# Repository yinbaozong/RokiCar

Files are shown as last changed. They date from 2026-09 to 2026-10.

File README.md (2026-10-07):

# RokiCar

**三轮全向移动，六边形车身，可打印、可改造的小型机器人。**

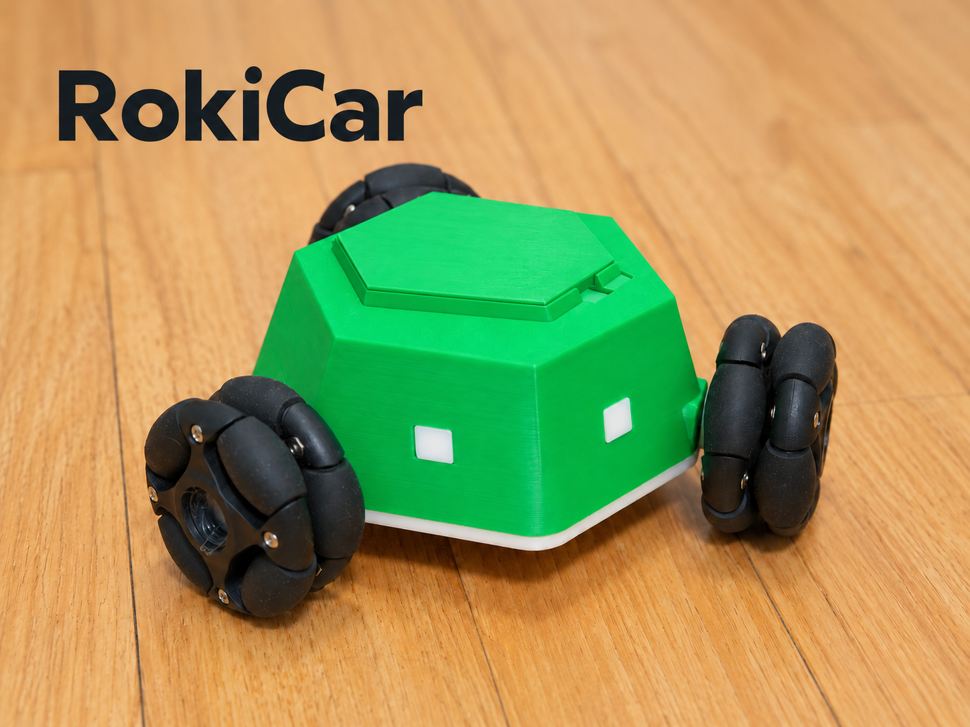
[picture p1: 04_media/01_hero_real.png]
实拍优化封面


当前：V8 外壳与顶盖、Android 1.22.0、三文件 MicroPython 程序。仓库公开，更新日期 2026-10-08。内部结构和轮组不变；顶盖取消定位销，保留一组磁吸。

## 下载与复刻

- [最新 Release / 全部附件](https://github.com/yinbaozong/RokiCar/releases/latest)
- [复刻指南 PDF](05_docs/RokiCar_复刻指南.pdf)：元器件、图片、装配、AI 刷写和首次校准。
- [Android APK 直接下载](https://github.com/yinbaozong/RokiCar/releases/latest/download/RokiCar-Controller-v1.22-debug.apk)
- [Roki 固件 ZIP](https://github.com/yinbaozong/RokiCar/releases/latest/download/RokiCar-Firmware-20261008.zip)
- [V8 模型 ZIP](https://github.com/yinbaozong/RokiCar/releases/latest/download/RokiCar-V8-Models.zip)
- [快速开始](05_docs/QUICK_START.md) · [物料与采购链接](05_docs/BOM.md) · [打印装配](05_docs/PRINT_AND_ASSEMBLY.md)

优先将固件交给能够访问本机终端和 USB 串口的 AI，例如 Codex、Claude Code、Trae、WorkBuddy，或 DeepSeek 搭配本地 Agent/Harness。安装 Python 和 mpremote，交给 AI 备份、上传、回读校验；用户确认重启和实车动作。详见 [刷写教程](05_docs/用户刷写教程.md) 和 [AI 提示词](05_docs/交给AI刷写.txt)。

## 最新机械与物料

- 车壳、顶盖：01_model/cad、01_model/print；原底壳为 01_model/cad/04_original_base.step。
- 顶盖每侧间隙 0.40 mm，围边厚 1.60 mm，无定位销。
- Ø8×2 mm 磁铁整车 10 颗：顶盖一组 2 颗、底壳四组 8 颗。
- N20 电机：6 V / 200 rpm，3 台；47 mm 全向轮 3 只；DRV8833 1 块。
- 电机螺丝 M1.6×3 mm 共 6 颗；BT 自攻规格为按孔位提出的试配建议，见 BOM。

## 最新接线与图片

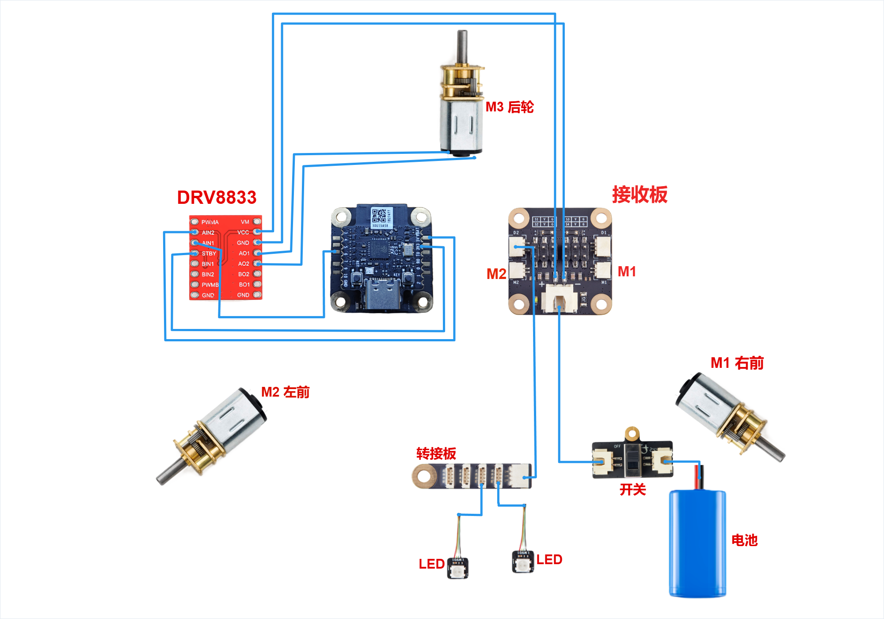
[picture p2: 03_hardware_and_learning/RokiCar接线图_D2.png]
作者确认的 D2 接线图


M1 右前、M2 左前、M3 后轮；LED 转接板 IN 接 D2，作者确认正常，固件灯控定义保持原样。逐项连接与电源说明见 [硬件接线](05_docs/HARDWARE_CONNECTIONS.md)。旧 SVG 和旧双驱动资料仅作学习参考。

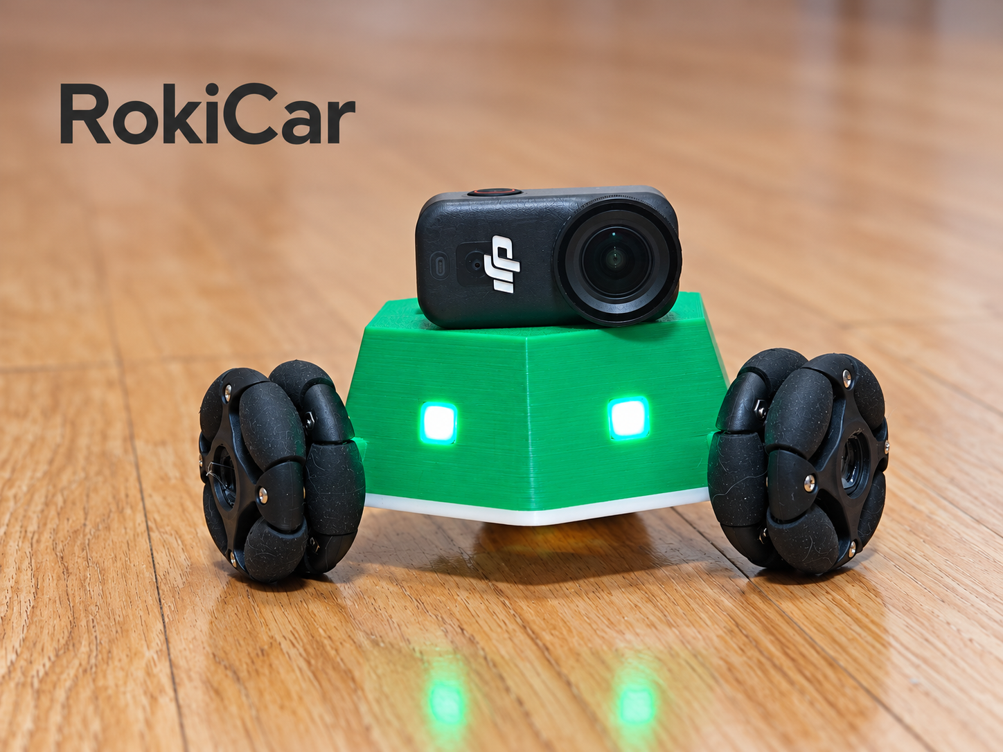
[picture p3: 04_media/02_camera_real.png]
相机搭载实拍优化


相机为额外配件，未交付图传、云台或专用磁吸相机支架。基础功能和实验功能见 [功能状态](05_docs/FEATURES_AND_ROADMAP.md)。

## 文档与验证

[项目手册](RokiCar_项目手册.md) · [MakerWorld 正文](05_docs/MAKERWORLD_DESCRIPTION.md) · [软件指南](05_docs/SOFTWARE_GUIDE.md) · [发布清单](05_docs/PUBLISH_FILES.md)

V8 几何与打印网格检查已记录在 01_model/docs。启动文件回归、语法与依赖检查通过；APK 使用既有 1.22.0 文件。本轮没有实车刷写或重新试打，按 PDF 完成文件回读、重启与架空校准后再低速落地。

原创内容采用 [MIT](LICENSE)，第三方组件见 [说明](THIRD_PARTY.md)。欢迎反馈打印配合、接线、兼容性和改造经验。

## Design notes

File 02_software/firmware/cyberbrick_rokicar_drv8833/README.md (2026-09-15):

# CyberBrick + DRV8833 三轮全向底盘测试程序

这个目录是给 CyberBrick Controller Core 用的 MicroPython 程序。

刷入后核心板会创建热点：

```text
WiFi: RokiCar
Password: 12345678
URL: http://192.168.4.1/
```

手机连接热点后打开网页，可以测试前进、后退、横移、旋转。

第一次测试必须把小车架空，不要让轮子落地。

## 硬件需求

- CyberBrick Controller Core x1
- DRV8833 双路电机驱动板 x2
- 6V DC 减速电机 x3
- 6V 电机电源

一块 DRV8833 只能控制两个 DC 电机。三轮小车需要两块 DRV8833。

## 引脚分配

| 轮子 | CyberBrick GPIO | DRV8833 输入 |
|---|---|---|
| W1 左前轮 | GPIO3 / GPIO2 | DRV-A AIN1 / AIN2 |
| W2 右前轮 | GPIO1 / GPIO0 | DRV-A BIN1 / BIN2 |
| W3 后轮 | GPIO21 / GPIO20 | DRV-B AIN1 / AIN2 |

如果某个轮子方向反了，优先改 `main.py` 里的 `MOTOR_SIGN`，不要急着重焊。

## 电机输出

| 轮子 | DRV8833 输出 |
|---|---|
| W1 左前轮 | DRV-A AO1 / AO2 |
| W2 右前轮 | DRV-A BO1 / BO2 |
| W3 后轮 | DRV-B AO1 / AO2 |

DRV-B 的 BO1/BO2 空着备用。

## 电源

| DRV8833 引脚 | 连接 |
|---|---|
| VM | 6V 电机电源正极 |
| GND | 6V 电源负极 + CyberBrick GND |
| STBY | CyberBrick 3V3 |
| NC | 不接 |

必须共地：CyberBrick GND 和 DRV8833 GND 要连在一起。

不要把电机直接接 CyberBrick。

## 上传

如果板子正在跑官方 CyberBrick RC 程序，需要先在串口里按 Ctrl+C 进入 REPL。

备份官方启动文件：

```powershell
mpremote connect COM9 resume fs cp :boot.py backup_boot.py
```

上传本程序：

```powershell
mpremote connect COM9 resume fs cp firmware\cyberbrick_rokicar_drv8833\main.py :main.py
mpremote connect COM9 resume fs cp firmware\cyberbrick_rokicar_drv8833\boot.py :boot.py
mpremote connect COM9 resume reset
```

恢复官方启动文件：

```powershell
mpremote connect COM9 resume fs cp backup_boot.py :boot.py
mpremote connect COM9 resume reset
```

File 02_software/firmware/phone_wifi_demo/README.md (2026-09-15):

# CyberBrick Phone WiFi Demo

这个 demo 只测试手机连接链路，不驱动电机。

刷入后 CyberBrick 会创建热点：

```text
WiFi: RokiCar-Demo
Password: 12345678
URL: http://192.168.4.1/
```

手机连接热点后打开网页，点击按钮时板载灯会闪一下，页面会显示收到的 `vx / vy / rot`。

## 上传

先关闭 CyberBrick 客户端，否则串口可能被占用。

查看可用串口：

```powershell
Get-PnpDevice -Class Ports
```

上传到指定串口，例如 `COM9`：

```powershell
.\firmware\phone_wifi_demo\upload.ps1 -Port COM9
```

如果要恢复官方 CyberBrick 程序，需要重新用 CyberBrick 官方客户端或官方固件流程刷回。

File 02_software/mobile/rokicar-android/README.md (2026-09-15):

# RokiCar Android

## 1.22.0

- 项目、APP、Android 包名和 Wi-Fi 热点统一改为 `RokiCar`。
- Android applicationId/namespace 改为 `com.rokicar.controller`，新版会与旧版并存安装。
- 固件升级后热点名统一为 `RokiCar`，控制地址仍为 `ws://192.168.4.1/ws`。

## 1.21.0

- 灯控首次连接自动补发状态查询（750ms 间隔，最多 10 次），不再依赖一次回复。
- 最新灯光命令未确认时每 500ms 重试，最多发送 4 次；旧状态不会覆盖最新操作，断线取消待发命令。
- AI 页只显示“待开发中”，关闭原生语音监听；返航顶部标注“实验功能”。
- 移除设置页闭环方形路径按钮及其事件处理。
- 使用 1.20 核心板程序，无需重新刷机。连接恢复、确认重试和断线取消三项模拟测试通过，仍需真机确认首次开灯效果。

## 1.20.0

- 设置页新增 RGB 灯光开关、颜色及亮度；两个灯同步变化。
- 需要同步上传 `firmware/cyberbrick_rokicar_m1m2_plus_drv8833/main.py`。
- CN301 IN 信号接 S1 / GPIO3，正极接稳压 5V，负极共地；D1/D2 仍用于第三电机。
- 协议类型 12，三个 int16 字段为 R/G/B（0–255）；全零关闭。四个输出统一设色，开机默认关闭。
- 灯控不更新运动超时计时；断线重连只读取灯状态，不重放开灯命令。
- 软件验证通过后仍需连接实物验证 CN301 输出和颜色顺序。

## 1.19.0

- Wi-Fi RSSI 保持每 `50ms` 读取和绘图，即 20Hz 界面刷新。
- 返航页新增读取频率、数值变化频率和数据年龄；原始值保持整数，平滑曲线显示一位小数。
- 灰线显示原始 RSSI，绿线显示滤波结果；返航趋势只接收真正发生变化的读数，避免重复缓存值被当成新证据。

## 1.18.0

- 横屏控制改为两只清晰的圆形摇杆，并显式绘制摇杆头，修复真机只显示轨道的问题。
- 左摇杆限定纵向油门，右摇杆限定横向转向；底部原地旋转按钮保持左右分区。

## 1.17.0

- 横屏双控制改为两个连续滑块：左侧纵向油门，右侧横向转向，支持双拇指同时拖动。
- 删除横屏四方向按键；原地左转和右转改为底部左右分区，退出键单独置顶。

## 1.16.0

- 横屏驾驶改为拇指分区：移动键固定贴近左侧，原地旋转和退出固定贴近右侧。
- 陀螺仪启动后自动开启平移，不再显示平移开关、姿态模拟和手动握姿校准。
- 航向转向独立切换：开启时只旋转，关闭后立即恢复前后左右平移。
- 返航终点 RSSI 默认修正为 `-35 dBm`，并修复首次启动被错误设成 `-20 dBm` 的问题。

## 1.15.0

- 双控制新增独立横屏驾驶界面：前进、后退、左移、右移、原地左转、原地右转和退出。
- 横屏控制按住才运动，松手、取消触摸、退出、后台和急停都会停车。
- 普通页面改为原生纵向滚动，横屏控制不再与页面滚动争夺手势。

## 1.13.0

- 陀螺仪模式新增手机航向跟随：校准时记录手机方位，左右旋转手机会让小车转向。
- 使用手机目标角度、虚拟车头积分和比例减速控制，误差进入 4° 死区后停止旋转。
- 航向数据超过 500ms 未更新时立即清零旋转命令。
- 这是无车载 IMU 的开环估算；轮胎打滑后可点“校准握姿”重新归零。

## 1.12.0

- “倾斜”模式改名为“陀螺仪”，固定输出纯平移与 `ROT=0`。
- 双控制转向上限由 27% 提升到 35%。
- 返航终点 RSSI 可手动设置，并显示最近约 60 秒实时曲线。
- RSSI 读取请求提升到 50ms；实际更新频率仍由 Android Wi-Fi 驱动决定。
- AI 页增加实时语音识别文字，并提示 RokiCar 无互联网时需要开启移动数据。

真正的无头模式需要车载 IMU 或其他车体航向反馈。当前手机传感器只能控制平移方向，无法测量车体因轮差产生的偏航。

## 1.11.0 测试版

安装包：`E:\三轮小车-麦克纳姆林\RokiCar-Controller-v1.11-debug.apk`

手机连接 `RokiCar` Wi-Fi 后打开 App。底部页面分为操控、AI、返航、设置与校准。

首次升级必须先把三只轮架空至少 10mm，然后在“设置与校准 > 完整电机标定向导”依次完成：

1. 点 M1、M2、外接板，确认它们对应 W1 左前、W2 右前、W3 后轮。
2. 观察每轮实际方向并选择“与图一致/相反”。当前故障现象高度提示 W3 需要反向，但请以实车观察为准。
3. 对每个物理端口运行 PWM 递增，连续稳定转动时点“已稳定”。
4. 架空预览前进、右移、原地右转，全部正确后保存。
5. 再运行三轮各五秒计圈，计算并保存速度增益。

方形测试现在按前进、右移、后退、左移执行，每边 5 秒、间隔 250ms，所有段 `ROT=0`。返航以反向轨迹为主，达到自适应 RSSI 目标立即停车；RSSI 连续恶化至少 3dB 时暂停并做四方向局部测向。

AI 语音配置只需一个阿里云百炼 API Key，模型为 `paraformer-realtime-v2`；DeepSeek Key 单独填写。心形、三角形、方形和五角星由 App 本地生成，执行前必须预览确认，并要求先完成距离标定。

原生 Android 控制器，直接连接 CyberBrick 的 `ws://192.168.4.1/ws`。不依赖 DCloud，项目可直接用 Android Studio 打开。

## 安装包

当前版本：`1.10.0`

```text
E:\三轮小车-麦克纳姆林\RokiCar-Controller-v1.10-debug.apk
```

USB 调试安装：

```powershell
adb install -r "E:\三轮小车-麦克纳姆林\RokiCar-Controller-v1.10-debug.apk"
```

手机先连接 `RokiCar` Wi-Fi，再打开 App。界面底部有四个分栏：

- `操控`：单摇杆、双控制、手机倾斜、速度档位和原地旋转。
- `AI 助手`：本地唤醒词“小麦小麦”、多轮对话记录、文字指令及云端配置。
- `返航`：轨迹回放、Wi-Fi 辅助判断、方形路径和距离标定。
- `设置`：重新连接和三轮五秒计圈校准。

红色方形按钮是全局急停，切换任何分栏也会先停车。

返航会从第一次移动开始持续保存最多十分钟的控制轨迹，App 重启后仍可恢复。返回时先按原速度、反序执行尚未回放的轨迹，并逐段删除已完成部分；只有回放后的信号明显弱于出发点基线，才用四方向 Wi-Fi 试探作局部修正。Wi-Fi RSSI 只能辅助判断远近，不能提供绝对方向。

闭环方形测试位于 `设置`，按前进、右移、后退、左移运行，每边 3.5 秒，理论终点为起点。没有编码器或视觉定位时，落地误差仍需通过轮速校准降低，软件无法测得真实厘米级位置。

## 小麦语音

语音链路为：本地 `sherpa-onnx` 唤醒词检测 → 阿里云一句话识别 → DeepSeek 受限工具决策 → App 校验动作 → CyberBrick 执行 → Android TTS 回复。

1. 在 `AI 助手 > AI 云端配置` 填写阿里云 AppKey 和临时 Token。
2. 填写 DeepSeek API Key。未填写时只支持本地基础移动指令。
3. 点击“安全保存到本机”，再开启“小麦小麦”监听并允许麦克风权限。
4. 连续说“小麦小麦”，听到“我在”后再说完整要求。

密钥使用 Android Keystore 加密保存，不写入 APK。阿里云临时 Token 过期后需要重新填写。DeepSeek 只能选择受限的移动、旋转、停车和返航工具，单次运动最长五秒，不能直接生成 PWM 或 GPIO 指令。

## 构建

```powershell
.\gradlew.bat :app:assembleDebug
```

Gradle 输出：

```text
app\build\outputs\apk\debug\app-debug.apk
```

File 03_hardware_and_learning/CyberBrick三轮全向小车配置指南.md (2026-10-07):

> 历史学习资料：当前接线、灯口和轮位请以 [最新 D2 接线说明](../05_docs/HARDWARE_CONNECTIONS.md) 与 [接线图](RokiCar接线图_D2.png) 为准。

# CyberBrick 三轮全向小车配置指南

日期：2026-07-05

## 1. 先说结论

用 CyberBrick 复刻三轮全向小车是可行的，但最终版需要写一点 MicroPython。

原因很简单：CyberBrick 官方接收扩展板只有 M1、M2 两路 DC 电机口，而三轮全向车需要 3 个独立 DC 电机同时正反转、调速。官方图形化配置适合两轮差速车、舵机、灯效和简单动作；三轮全向车需要把摇杆输入实时换算成三个轮子的速度，这一步就是三轮逆运动学，必须用代码做。

你不需要从零学完整编程。我们采用“官方 CyberBrick 配置 + 小段 MicroPython 控制程序”的路线。

## 2. 推荐架构

```text
CyberBrick 发射端
  核心板 + 发射扩展板 + 摇杆/按键
        |
        | CyberBrick 无线通信
        v
CyberBrick 接收端
  核心板 + 接收扩展板
        |
        | GPIO / PWM 信号
        v
外部三路电机驱动板
        |
        v
三个 DC 减速电机 + 47 mm 全向轮
```

接收扩展板的 M1/M2 可以先用来做两路电机验证，但最终车最好用外部三路驱动板统一驱动三个电机。

## 3. 为什么不能只靠官方接收板

官方接收扩展板的输出资源大致是：

- 2 路 DC 电机口：M1、M2。
- 4 路舵机口：S1-S4。
- 2 路 WS2812 灯口。

三轮全向底盘需要：

- W1 左前轮：一路 DC 电机。
- W2 右前轮：一路 DC 电机。
- W3 后轮：一路 DC 电机。

也就是至少 3 路 DC 电机。舵机口不能直接当普通 DC 电机 H 桥用，因为普通 DC 电机需要方向控制和 PWM 功率驱动。

## 4. 控制方式选择

### 推荐第一版：CyberBrick 遥控器控制

先用你手里的 CyberBrick 发射端做遥控器。这样不需要先做手机 App，调试更快。

建议遥控器输入：

- 左摇杆 X：左右平移。
- 左摇杆 Y：前后平移。
- 右摇杆 X 或单轴摇杆：原地旋转。
- 一个按钮或三段开关：速度档位。

### 第二版：手机控制

等底盘稳定跑起来后，再做手机控制。手机控制可以走 WiFi UDP 或 CyberBrick 自带 App/配置能力，但不建议第一步就上手机控制，因为变量太多。

## 5. 配置步骤

### 第 1 步：确认官方 CyberBrick 能正常配对

在 CyberBrick 桌面端或手机端中：

1. 给发射端核心板接发射扩展板。
2. 给接收端核心板接接收扩展板。
3. 分别上电。
4. 在 CyberBrick 软件里找到两个核心板。
5. 完成发射端和接收端配对。

这一步只验证官方无线链路，不接三轮底盘。

### 第 2 步：用官方 M1/M2 做两电机测试

先只接两个电机到接收板 M1/M2。

目标：

- 摇杆能控制 M1 正反转。
- 摇杆能控制 M2 正反转。
- 断开摇杆时电机能停止。

这一步是为了确认 CyberBrick 的发射、接收、电机口、供电都正常。

### 第 3 步：接外部三路电机驱动板

最终建议用外部三路驱动板，或用两个 DRV8833 双路模块组成 3 路。

每个普通 DC 电机需要两个控制信号：

```text
W1: IN1, IN2
W2: IN3, IN4
W3: IN5, IN6
```

供电原则：

- 电机电源单独用 6 V 降压模块。
- CyberBrick 按官方方式供电。
- CyberBrick GND 和电机驱动板 GND 必须共地。
- 不要用 CyberBrick 核心板的小电源脚直接给三个电机供电。

### 第 4 步：写 MicroPython 三轮混控

代码要做三件事：

1. 读取发射端摇杆值：`vx`、`vy`、`rot`。
2. 根据三轮逆运动学算三个轮子的速度。
3. 输出到三路电机驱动板。

本项目的定版轮位公式：

```python
w1 = -0.5 * vx - 0.866 * vy + rot_gain * rot
w2 = -0.5 * vx + 0.866 * vy + rot_gain * rot
w3 =  1.0 * vx               + rot_gain * rot
```

然后把 `w1/w2/w3` 限幅到 `-1.0 ~ +1.0`，再变成 PWM。

### 第 5 步：悬空测试

小车先架起来，轮子不要碰桌面。

测试顺序：

1. 前进：两个前轮一正一反，后轮接近不动。
2. 右移：后轮贡献最大，两个前轮同向小一点。
3. 原地旋转：三个轮子同向转。
4. 松开摇杆：三个轮子全部停止。

如果某个轮方向反了，只改程序里的符号，不先改结构。

### 第 6 步：低速落地测试

第一次落地时把最大 PWM 限制在 40%。

测试顺序：

1. 原地旋转。
2. 前后移动。
3. 左右横移。
4. 斜向移动。
5. 边移动边旋转。

底盘能稳定运动后，再装手机托盘和舵机云台。

## 6. 你需要准备的东西

必需：

- CyberBrick 发射端核心板 + 发射扩展板。
- CyberBrick 接收端核心板 + 接收扩展板。
- 三个 6 V 200 RPM 左右 DC 减速电机。
- 三个 47 mm 全向轮。
- 外部三路 DC 电机驱动板，或 DRV8833 双路模块 x2。
- 6 V 3 A 以上降压模块。
- 电池和主开关。

建议：

- 先不要接手机和云台。
- 先不要做完整外壳。
- 先把三轮底盘跑顺。

## 7. 配置路线选择

### 不写代码

只能做两轮差速车，或者做非常别扭的两电机/舵机混合方案。不适合三轮全向底盘。

### 写少量代码

推荐。使用 CyberBrick 官方发射/接收链路，只在接收端写三轮混控。代码量不大，但能得到真正的三轮全向运动。

### 完全自定义手机控制

后续版本再做。可以让 CyberBrick 核心板开 WiFi 或接收 UDP，但第一版不推荐先做手机控制。

## 8. 当前下一步

现在不要急着写完整程序。下一步按这个顺序做：

1. 在 CyberBrick 软件里完成发射端和接收端配对。
2. 用官方 M1/M2 接两个电机，确认遥控链路和电机输出正常。
3. 选定外部电机驱动板型号。
4. 确认 CyberBrick 核心板可用 GPIO 引脚。
5. 再写三轮混控 MicroPython。

这样走最稳，不会一上来就把机械、电源、无线、代码四件事搅在一起。

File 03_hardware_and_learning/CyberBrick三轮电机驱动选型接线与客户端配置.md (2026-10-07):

> 历史学习资料：当前接线、灯口和轮位请以 [最新 D2 接线说明](../05_docs/HARDWARE_CONNECTIONS.md) 与 [接线图](RokiCar接线图_D2.png) 为准。

# CyberBrick 三轮电机驱动选型、接线与客户端配置

日期：2026-07-05

## 1. 最终推荐

买两个 `DRV8833 双路直流电机驱动模块`。

原因：

- 一个 DRV8833 模块可以驱动 2 个 DC 电机。
- 两个模块一共 4 路，用其中 3 路，剩 1 路备用。
- 模块很小，容易塞进 135 mm 轮心圆底盘。
- 支持 3.3 V 逻辑，适合 CyberBrick 核心板的 ESP32-C3。
- 电机电压覆盖 6 V 小减速电机场景。
- 比 L298N 小很多，效率也高很多。

搜索关键词：

```text
DRV8833 双路电机驱动模块
DRV8833 2路 直流电机驱动板 3V 10V
DRV8833 dual motor driver module
```

不要买：

- L298N：太大、压降大、发热，低压小车不划算。
- L9110S：便宜但余量小，不适合你后面 700-800 g 负载。
- 只写“电机驱动板”但没写芯片和电流参数的杂板。

## 2. 备选方案

如果你想一块板解决，也可以买 `四路 TB6612FNG 直流电机驱动板`。

搜索关键词：

```text
四路 TB6612FNG 直流电机驱动板
TB6612 四路电机驱动模块
Quad Motor Driver TB6612FNG
```

优点是一块板更整洁。缺点是板子更大，线也不一定少；很多四路板是 Arduino Shield 形式，不适合直接塞进你现在这个紧凑底盘。

所以第一版还是推荐：`DRV8833 x2`。

## 3. 重要参数

按官方和常见模块资料：

| 驱动 | 路数 | 电机电压 | 单路电流 | 适合本项目 |
|---|---:|---:|---:|---|
| DRV8833 双路模块 | 2 | 约 2.7-10.8 V | 约 1.2-1.5 A 连续，2 A 左右峰值 | 推荐 |
| TB6612FNG 双路模块 | 2 | 约 2.5-13.5 V | 约 1.2 A 连续，3.2 A 峰值 | 可用 |
| 四路 TB6612FNG 板 | 4 | 约 2.5-13.5 V | 约 1.2 A 连续 | 可用但偏大 |
| L298N | 2 | 高压范围大 | 发热大、压降大 | 不推荐 |

你买电机时要看堵转电流。如果单电机堵转电流明显超过 1.5-2 A，就不要用小 DRV8833，得换更大电流的驱动。

## 4. 接线总原则

三件事必须记住：

1. 电机不能直接接 CyberBrick 核心板。
2. 电机电源和 CyberBrick 供电可以分开，但 GND 必须共地。
3. 先只接一个电机测试，确认方向和发热，再接三个。

推荐供电：

```text
2S 电池 7.4 V
  |
  +-- 6 V 降压模块 --> DRV8833 VM / 电机电源
  |
  +-- CyberBrick 官方供电 / 5 V 稳压

CyberBrick GND 必须连接 DRV8833 GND
```

## 5. DRV8833 x2 接线表

这里假设两个 DRV8833 模块分别叫 `DRV-A` 和 `DRV-B`。

### 电机输出

| 轮子 | 驱动模块 | 输出端 |
|---|---|---|
| W1 左前轮 | DRV-A | AOUT1 / AOUT2 |
| W2 右前轮 | DRV-A | BOUT1 / BOUT2 |
| W3 后轮 | DRV-B | AOUT1 / AOUT2 |
| 备用 | DRV-B | BOUT1 / BOUT2 空着 |

如果轮子方向反了，优先在程序里改符号；也可以交换该电机的两根输出线。

### 电源

| DRV8833 引脚 | 接哪里 |
|---|---|
| VM / VIN / Motor V+ | 6 V 电机电源正极 |
| GND | 电机电源负极 + CyberBrick GND |
| VCC | 如果模块有 VCC，接 CyberBrick 3V3 |
| SLEEP / nSLEEP | 如果模块有这个脚，接 3V3 拉高 |

不同商家的 DRV8833 模块命名不完全一样。只要认准：电机电源、地、输入脚、输出脚。

## 6. CyberBrick 到 DRV8833 的信号线

第一版建议用 6 根控制线，每个电机 2 根：

| 轮子 | DRV8833 输入 | CyberBrick 建议 GPIO | 物理取线建议 |
|---|---|---:|---|
| W1 左前轮 | IN1 | GPIO3 | 接收板 S1 信号脚或核心板焊盘 |
| W1 左前轮 | IN2 | GPIO2 | 接收板 S2 信号脚或核心板焊盘 |
| W2 右前轮 | IN1 | GPIO1 | 接收板 S3 信号脚或核心板焊盘 |
| W2 右前轮 | IN2 | GPIO0 | 接收板 S4 信号脚或核心板焊盘 |
| W3 后轮 | IN1 | GPIO21 | 核心板右侧焊盘 |
| W3 后轮 | IN2 | GPIO20 | 核心板右侧焊盘 |

注意：

- 如果使用 S1-S4 的信号脚，就不要在 CyberBrick 客户端里把 S1-S4 配置成舵机。
- S1-S4 的 V 脚不要接到 DRV8833 的 VM。DRV8833 的 VM 要接 6 V 电机电源。
- GPIO20/GPIO21 是串口相关脚。如果后面发现调试串口冲突，可以把 W3 改到 GPIO4/GPIO5，但那会和官方 M1 电机控制脚重叠，需要实测。
- GPIO8 是板载 RGB LED，GPIO9 是用户按键，不建议拿来驱动电机。

## 7. CyberBrick 客户端怎么配置

### 7.1 先做官方链路验证

先不要接外部驱动板。

在 CyberBrick 客户端里：

1. 新建项目。
2. 添加/配对发射端核心板。
3. 添加/配对接收端核心板。
4. 发射端添加摇杆模块。
5. 接收端先用官方 M1/M2 接两个电机做测试。
6. 确认摇杆能控制两个电机正反转。

这一步只证明 CyberBrick 发射、接收、供电、电机口都正常。

### 7.2 外部三路驱动时的配置

最终三轮全向底盘时：

- 接收端不要再把 M1/M2 当正式驱动。
- S1-S4 如果被我们拿来当 GPIO，就不要配置成舵机。
- 在接收端添加 `Code`，用于测试外部 GPIO 和驱动板。

客户端大致流程：

1. 进入你的项目。
2. 选择接收端 Receiver。
3. 找到 `Code` 或代码模块。
4. 点击 `Add` 新增代码片段。
5. 粘贴测试代码。
6. 给发射端按钮添加事件。
7. 事件动作选择 `Code`，选择刚才的代码片段。
8. 保存并发送配置到设备。
9. 按按钮触发测试。

## 8. 客户端 Code 测试片段

下面这段只用于测试外部驱动板，不是最终摇杆控制。

先把小车架空，轮子不要碰桌面。

```python
from machine import Pin, PWM
import uasyncio as asyncio

FREQ = 1000
MAX_DUTY = 65535

W1A = PWM(Pin(3), freq=FREQ)
W1B = PWM(Pin(2), freq=FREQ)
W2A = PWM(Pin(1), freq=FREQ)
W2B = PWM(Pin(0), freq=FREQ)
W3A = PWM(Pin(21), freq=FREQ)
W3B = PWM(Pin(20), freq=FREQ)

def duty(x):
    x = max(0, min(1, abs(x)))
    return int(MAX_DUTY * x)

def set_pair(a, b, speed):
    if speed > 0:
        a.duty_u16(duty(speed))
        b.duty_u16(0)
    elif speed < 0:
        a.duty_u16(0)
        b.duty_u16(duty(speed))
    else:
        a.duty_u16(0)
        b.duty_u16(0)

def stop_all():
    set_pair(W1A, W1B, 0)
    set_pair(W2A, W2B, 0)
    set_pair(W3A, W3B, 0)

set_pair(W1A, W1B, 0.35)
set_pair(W2A, W2B, 0)
set_pair(W3A, W3B, 0)
await asyncio.sleep(1.5)
stop_all()
```

测试顺序：

1. 改代码，只让 W1 转。
2. 改代码，只让 W2 转。
3. 改代码，只让 W3 转。
4. 每个轮子都能正反转后，再做混控。

## 9. 为什么客户端 Code 不能直接完成最终摇杆混控

我看了 CyberBrick 官方 RC 代码。官方 `MotorsController` 只封装了 M1/M2 两个电机；客户端的 Code 片段可以触发运行代码，但默认执行环境没有直接把实时摇杆 `remote_data` 暴露给代码片段。

所以：

- Code 片段适合做外部驱动板测试、固定动作、启动/停止脚本。
- 真正的三轮全向连续摇杆控制，最好做成接收端自定义 MicroPython 程序，或者修改官方 `app_rc` 里的控制逻辑。

这不是坏事。我们仍然先用客户端完成配对、摇杆校准和硬件验证，然后进入自定义代码阶段。

## 10. 最终三轮混控逻辑

等三个电机都测试通过后，最终代码要做：

```python
w1 = -0.5 * vx - 0.866 * vy + rot_gain * rot
w2 = -0.5 * vx + 0.866 * vy + rot_gain * rot
w3 =  1.0 * vx               + rot_gain * rot
```

然后归一化限幅：

```python
scale = max(1, abs(w1), abs(w2), abs(w3))
w1 /= scale
w2 /= scale
w3 /= scale
```

最后分别输出到三个 DRV8833 通道。

## 11. 我的下一步建议

现在按这个顺序做：

1. 买 `DRV8833 双路电机驱动模块 x2`。
2. 先只接 W1 一个电机。
3. 用客户端 Code 片段测试 W1 正反转。
4. 再接 W2、W3。
5. 三个轮子单独测试都通过后，再写真正的三轮混控程序。

不要一开始就把三个电机、手机、舵机、电池全接上。先让一个轮子听话，整车就稳了一半。

## 12. 参考资料

- DRV8833 官方数据手册：<https://www.ti.com/lit/gpn/DRV8833>
- Pololu DRV8833 双路驱动说明：<https://www.pololu.com/product/2130>
- SparkFun TB6612FNG 接线指南：<https://learn.sparkfun.com/tutorials/tb6612fng-hookup-guide/all>
- DFRobot 四路 TB6612FNG 驱动板：<https://wiki.dfrobot.com.cn/_SKU_DRI0039_Quad_Motor_Driver_Shield_for_Arduino%E5%9B%9B%E8%B7%AF%E7%9B%B4%E6%B5%81%E7%94%B5%E6%9C%BA%E9%A9%B1%E5%8A%A8%E6%89%A9%E5%B1%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>
- CyberBrick 官方控制核心源码：<https://github.com/CyberBrick-Official/CyberBrick_Controller_Core>
- CyberBrick MotorsController API：<https://makerworld.com/en/cyberbrick/api-doc/cyberbrick_core/lib/MotorController.html>

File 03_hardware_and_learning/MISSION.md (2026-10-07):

> 历史学习资料：当前接线、灯口和轮位请以 [最新 D2 接线说明](../05_docs/HARDWARE_CONNECTIONS.md) 与 [接线图](RokiCar接线图_D2.png) 为准。

# Mission: Three-Wheel Omni Car

## Why
Build a cost-effective three-wheel omni car based on Bambu CyberBrick that can carry a phone, camera/servo payload, and be controlled from a phone. Learning the kinematics matters because the chassis will not move correctly unless the wheel layout, motor directions, and control code agree.

## Success looks like
- Model a compact three-wheel chassis from fixed wheel-center coordinates.
- Explain why a desired chassis motion becomes three different wheel speeds.
- Translate joystick commands into motor PWM values on CyberBrick MicroPython.
- Debug wrong wheel directions without redesigning the chassis.

## Constraints
- Keep the design cost-effective and printable.
- Use a three-layer structure: lower mechanical/electrical plate, middle CyberBrick/control plate, upper phone/camera/servo payload.
- Prefer deterministic diagrams, HTML simulation, and code-native artifacts over decorative visuals.

## Out of scope
- Full closed-loop encoder control for the first chassis version.
- FPV video streaming on the first driveable prototype.

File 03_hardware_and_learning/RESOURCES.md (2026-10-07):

> 历史学习资料：当前接线、灯口和轮位请以 [最新 D2 接线说明](../05_docs/HARDWARE_CONNECTIONS.md) 与 [接线图](RokiCar接线图_D2.png) 为准。

# Three-Wheel Omni Car Resources

## Knowledge

- Local note: `C:\Users\win11\Documents\Obsidian Vault\三轮全向麦克纳姆轮小车复刻指南 - Three-wheel Omni-wheel Car Replication Guide.md`
  Use for: the project-specific replication notes, motor-speed assumptions, UDP protocol, and existing ESP32/UniApp examples.
- Local code: `E:\三轮小车-麦克纳姆林\相关资料\SLC_Camera_UDP_IMU\SLC_Camera_UDP_IMU\SLC_Camera_UDP_IMU.ino`
  Use for: the existing three-wheel UDP protocol, ESP32 motor output mapping, and IMU correction pattern.
- CyberBrick official repository: https://github.com/CyberBrick-Official/CyberBrick_Controller_Core
  Use for: CyberBrick MicroPython capabilities, ESP32-C3 quick reference, PWM, WiFi, and socket behavior.

## Wisdom

- First real-world test should be low-speed desk testing with the car suspended first, then wheels on the table. Use for: validating motor signs, wheel placement, and center-of-mass safety before adding the phone payload.

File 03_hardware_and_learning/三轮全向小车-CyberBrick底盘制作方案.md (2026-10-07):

> 历史学习资料：当前接线、灯口和轮位请以 [最新 D2 接线说明](../05_docs/HARDWARE_CONNECTIONS.md) 与 [接线图](RokiCar接线图_D2.png) 为准。

# 三轮全向小车 CyberBrick 底盘制作方案

日期：2026-06-28

## 0. 结论先行

你的目标是桌面为主、偶尔地面、整车约 800 g，并且希望用手机联网控制。方案定版如下：

- 轮子定为 47 mm 全向轮。
- 电机定为 6 V 200 RPM 金属减速电机，后续用软件限速做桌面低速档。
- 底盘采用三轮 Kiwi/Omni 布局，三个轮子中心在等边三角形顶点。
- 建模用的轮心圆半径 R = 67.5 mm，轮心圆直径 D = 135 mm。
- 47 mm 轮装上后的实际占地外接半径约 91 mm，实际占地外接直径约 182 mm。
- CyberBrick 标准接收扩展板只有 2 路 DC 电机口，三轮全向底盘需要 3 路电机，所以推荐方案是“CyberBrick 核心板 + 自制 3 路电机驱动小板”，不用标准接收板直接驱三轮。
- 第一版不做摄像头，不做闭环编码器；手机连小车 WiFi AP，发送 UDP 控制包，CyberBrick ESP32-C3 用 MicroPython 解算三轮速度并输出 PWM。

一句话版本：47 mm 轮 + 轮心圆直径 135 mm + 6 V 200 RPM 减速电机 + DRV8833 x2 + CyberBrick 核心板，是最稳的桌面复刻路线。

## 0.1 建模定版尺寸

坐标系定义：车体中心 C = (0, 0)，X 向右，Y 向前；两个前轮在前方，单后轮在后方。

| 项目 | 定版值 |
|---|---:|
| 轮子直径 | 47 mm |
| 轮子半径 | 23.5 mm |
| 轮心圆半径 R | 67.5 mm |
| 轮心圆直径 D | 135 mm |
| 三个轮心构成的等边三角形边长 | 116.9 mm |
| 装轮后的占地外接半径 | 91 mm |
| 装轮后的占地外接直径 | 182 mm |
| 上层手机托盘建议尺寸 | 175 x 90 mm |
| 手机放置方向 | 160 mm 长边沿车体前后方向，70 mm 宽边沿左右方向 |

轮心坐标：

| 轮位 | 极角 | X | Y | 电机轴/轮轴方向 | 轮子滚动方向 |
|---|---:|---:|---:|---:|---:|
| W1 左前轮 | 150 deg | -58.5 mm | +33.75 mm | 150 deg 径向 | 60 deg 切向 |
| W2 右前轮 | 30 deg | +58.5 mm | +33.75 mm | 30 deg 径向 | 120 deg 切向 |
| W3 后轮 | 270 deg | 0 mm | -67.5 mm | 270 deg 径向 | 0 deg 切向 |

建模时先画一个半径 67.5 mm 的辅助圆，把三个轮轴中心放在上表坐标。电机轴线从车体中心指向对应轮心，轮子的主动滚动方向与这条径向线垂直。电机正反方向不用在结构上纠结，最后在程序里调符号。

135 mm 轮心圆会比 150 mm 更紧凑，适合你的三层结构。注意一个边界：上层舵机、相机和手机的合成重心尽量不要超过车体中心前方 34 mm；如果云台很重，就把电池稍微后移一点来配平。

## 1. 轮径与电机转速选择

速度公式：

```text
车轮线速度 v = RPM / 60 * pi * 轮径
```

### 1.1 47 mm 全向轮

| 电机输出转速 | 理论最高车速 | 桌面 1.2 m 横穿时间 | 判断 |
|---:|---:|---:|---|
| 150 RPM | 0.37 m/s | 3.2 s | 很适合桌面，稳 |
| 187 RPM | 0.46 m/s | 2.6 s | 桌面/地面兼顾，推荐 |
| 200 RPM | 0.49 m/s | 2.4 s | 推荐，采购更常见 |
| 300 RPM | 0.74 m/s | 1.6 s | 桌面偏快，需要限速 |
| 400 RPM | 0.98 m/s | 1.2 s | 桌面太快，不推荐满速 |

47 mm 的好处是通过能力、抓地和机械空间都更好。带手机和几个舵机时，28 mm 会显得有点低趴，电机和底盘很容易贴近桌面。

最终定版：买 6 V 200 RPM 金属减速 N20/030 小减速电机。200 RPM 满速约 0.49 m/s，桌面调试时把最大 PWM 限到 60-70%，需要地面巡航时再放开。

### 1.2 为什么不选 28 mm 全向轮

| 电机输出转速 | 理论最高车速 | 桌面 1.2 m 横穿时间 | 判断 |
|---:|---:|---:|---|
| 150 RPM | 0.22 m/s | 5.5 s | 偏慢 |
| 300 RPM | 0.44 m/s | 2.7 s | 推荐 |
| 400 RPM | 0.59 m/s | 2.0 s | 可用，但需限速 |
| 500 RPM | 0.73 m/s | 1.6 s | 桌面偏快 |

本项目不采用 28 mm 轮。原因是手机和云台会把整车推到 700-800 g，28 mm 轮轴心只有 14 mm，高度、离地间隙和电机安装空间都偏紧，最后省下的尺寸不值得。

### 1.3 扭矩结论

800 g 平面移动不是大扭矩场景，真正要防的是启动打滑、堵转发热和结构变形。实际采购时看这三个指标：

- 额定电压：6 V 优先。
- 堵转电流：单电机最好不超过 1.5-2.0 A，方便用 DRV8833/TB6612。
- 输出轴：3 mm D 轴或常见 N20 D 轴，方便配联轴器。

不要买裸 030/130 高速电机直接带轮，一定买“电机 + 减速箱一体”的减速电机。

## 2. CyberBrick 适配方案

官方 CyberBrick 接收扩展板适合两轮差速车：它有 2 路 DC 电机口、4 路舵机口、2 路 WS2812 灯口。三轮全向车需要 3 路可正反转、可调速的 DC 电机，所以标准接收扩展板不够。

### 方案 A：推荐，CyberBrick 核心板 + 自制三路驱动板

结构：

```text
手机
  |
WiFi UDP
  |
CyberBrick Multi-Function Core Board（ESP32-C3 / MicroPython）
  |
6 路 PWM GPIO
  |
DRV8833 x2 或 TB6612FNG x2
  |
3 个 DC 减速电机
```

优点：

- 三轮全向运动学完整。
- 手机控制逻辑简单。
- 不受官方 2 路电机口限制。
- 后续可以加 IMU 做航向锁定。

缺点：

- 需要焊一块小驱动板或洞洞板。
- GPIO 需要根据你手里的 CyberBrick 核心板引出脚最终确认。

### 方案 B：不推荐，2 路 DC 电机 + 第三路连续舵机

第三个轮子用连续旋转舵机或舵机 PWM 转电机驱动，理论能跑，但三路动态响应不同，会导致平移歪、旋转飘，调起来很难受。除非只是演示，不建议这样做。

### 方案 C：标准 CyberBrick 两轮底盘

这就不是三轮全向车了，不符合你的目标。

## 3. 底盘几何设计

### 3.1 坐标和轮位

采用 120 度三轮全向布局：

```text
          W1 左前轮
             /\
            /  \
           /    \
        中心 C   \
           \    /
            \  /
             \/
          W2 右前轮

             W3 后轮
```

更准确地说，三个轮心放在同一个半径 67.5 mm 的圆上：

- W1 左前轮：150 度，坐标 (-58.5, +33.75) mm
- W2 右前轮：30 度，坐标 (+58.5, +33.75) mm
- W3 后轮：270 度，坐标 (0, -67.5) mm

每个轮子的滚动方向沿圆的切线方向，轮轴与车体半径近似垂直。三个轮子必须完全等距、等角，否则平移会歪。

### 3.2 尺寸建议

R 是轮心到车体中心的距离，等边三角形边长为：

```text
轮心三角形边长 = sqrt(3) * R
```

本项目定版：47 mm 轮用 R = 67.5 mm。外轮廓做成圆角三角形，最大占地直径约 182 mm。这样能放下手机托盘，又不会显得像一个过大的圆盘。

### 3.3 两层底盘结构

推荐两层结构，而不是一块薄板全塞进去：

```text
上层：手机托盘 / 舵机安装位 / CyberBrick 核心板
M3 铜柱或打印柱，高 25-35 mm
下层：三电机固定、驱动板、电池、开关
```

下层底盘：

- 3 mm 厚 PLA+/PETG，推荐 PETG 或 Bambu PLA Tough。
- 三个电机安装区做成长圆孔，允许 1-2 mm 位置微调。
- 电机轴心高度等于轮半径：47 mm 轮为 23.5 mm，28 mm 轮为 14 mm。
- 每个电机座旁边留扎带孔，防止螺丝松动后电机偏转。
- 中心留电池绑带槽，电池尽量低放。

上层托盘：

- 约 95 mm x 165 mm 手机放置区。
- 两条横向绑带槽或 TPU 防滑条。
- 舵机安装位放在前方或上方，尽量不要把重物悬在三角支撑区外。
- CyberBrick 核心板放中心偏上，USB-C 朝外，方便烧录。

### 3.4 防翻与重心

桌面小车最怕两件事：冲出桌边和手机把车带翻。设计上做三条限制：

- 软件最大速度默认 70%，调试阶段 40%。
- 手机中心必须落在三轮三角形内部。
- 电池放最底层，手机不要立起来，第一版平放。

## 4. 电气方案

### 4.1 电源

推荐：

- 电池：2S 7.4 V 锂电，1000-1500 mAh。
- 电机电源：6 V 3 A 降压模块，给三路电机驱动。
- 舵机电源：5-6 V 3 A 降压模块，视舵机规格而定。
- CyberBrick 核心板：按官方供电方式或 5 V 稳压供电。
- 所有 GND 必须共地。

不建议三路电机、舵机、核心板全部从一条细线供电。电机启动时压降会让 ESP32-C3 重启。

### 4.2 电机驱动

第一版驱动定为 DRV8833 双路模块 x2：

| 驱动 | 数量 | 优点 | 注意 |
|---|---:|---|---|
| DRV8833 双路模块 | 2 | 便宜，小，够桌面用 | 堵转别太久，电机电源单独降压 |

三轮共需要 6 根 PWM 控制线，即每个电机 IN1/IN2 各一根。ESP32-C3 总 PWM 通道数足够，但要避开 USB、Flash、板载功能占用引脚。最终以 CyberBrick 核心板 pinout 和丝印为准。

建议预留：

- 6 路 PWM：M1A/M1B/M2A/M2B/M3A/M3B
- 2 路 I2C：SDA/SCL，未来接 MPU6050/ICM42688
- 1 路电池电压检测 ADC
- 1 路蜂鸣器或状态灯

## 5. 控制协议与 MicroPython 路线

第一版不必上蓝牙。用 WiFi AP + UDP 最简单：

```text
CyberBrick 建立 WiFi 热点：RokiCar
手机连接 RokiCar
手机 App/网页发送 UDP 到 192.168.4.1:1234
数据格式：AG<角度>LG<速度>RO<旋转>
示例：AG90LG40RO50
停止：TT
```

这和你资料里的 UniApp/ESP32 代码一致，迁移成本最低。

控制量解释：

- AG：平移方向，0-359 度。
- LG：平移速度，0-60。
- RO：旋转，0-100，50 为不旋转，小于 50 一方向，大于 50 另一方向。

MicroPython 中转成归一化控制：

```python
angle = radians(AG)
move = LG / 60
rot = (RO - 50) / 50
vx = cos(angle) * move
vy = sin(angle) * move
```

然后做三轮逆运动学。按本文最终轮位，轮心角度为 150/30/270 度，公式可以写成：

```python
w1 = -0.5 * vx - 0.866 * vy + rot_gain * rot  # 左前轮
w2 = -0.5 * vx + 0.866 * vy + rot_gain * rot  # 右前轮
w3 =  1.0 * vx               + rot_gain * rot  # 后轮
```

归一化后输出到三路电机。

## 6. 第一版调试顺序

1. 只接 CyberBrick 核心板，确认 MicroPython REPL、WiFi AP、UDP 收包正常。
2. 接一个电机驱动和一个电机，写 `set_motor()`，验证正转、反转、刹车、滑行。
3. 三个电机悬空测试，发送 AG/LG/RO，看三轮方向是否符合预期。
4. 装轮子，低速落地，先测原地旋转。
5. 测前进/后退，如果歪，先交换电机正反，不要急着改公式。
6. 测左右平移，如果斜，检查三轮几何角度和轮轴切向。
7. 最后放手机和舵机负载，把最大速度从 40% 慢慢提高到 70%。

## 7. 采购清单

### 47 mm 推荐版

| 物料 | 规格 | 数量 |
|---|---|---:|
| 全向轮 | 47/48 mm，双层滚轮 | 3 |
| 减速电机 | 6 V，200 RPM，金属齿轮箱 | 3 |
| 电机驱动 | DRV8833 双路模块 | 2 |
| CyberBrick 核心板 | ESP32-C3 Multi-Function Core Board | 1 |
| 电池 | 2S 7.4 V，1000-1500 mAh | 1 |
| 降压模块 | 6 V 3 A 电机用 | 1 |
| 降压模块 | 5 V/6 V 3 A 舵机用 | 1 |
| 开关 | 2S 电池主开关 | 1 |
| 螺丝铜柱 | M2/M2.5/M3 组合 | 若干 |
| 防滑/绑带 | 手机绑带、电池绑带、TPU 垫 | 若干 |

### 28 mm 小轮版

把电机换成 300 RPM 左右。如果只有 400 RPM 可买，就在程序里限速。

## 8. 关键风险

- 标准 CyberBrick 接收板只有两路 DC 电机，不够三轮全向，这是最大的架构风险。
- 28 mm 轮轴心只有 14 mm 高，电机和底盘很容易贴地，不适合 800 g、带手机的车。
- 三轮开环一定会有轻微漂移，第一版可接受；想更稳，第二版加 IMU 航向锁定。
- 手机端控制必须有“松手即停”和“通信超时自动停”。建议 300 ms 没收到包就停车。
- 电机电源和核心板电源要隔离降压并共地，避免电机启动导致核心板重启。

## 9. 后续升级

第二版再做：

- MPU6050/ICM42688 航向锁定。
- 电池电压检测和低电量限速。
- 速度曲线：低速细腻，高速不窜。
- 桌边防跌落传感器。
- 编码器电机闭环。

第一版目标不要贪：先让 47 mm 三轮底盘用手机 UDP 稳定地前后、横移、原地旋转。这一步跑顺了，后面加舵机和玩法才有地基。

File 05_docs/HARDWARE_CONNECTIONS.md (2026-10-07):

# 接线：两台接接收板，第三台接 DRV8833

作者重新整理的接线图

**灯光连接：LED 转接板的 IN 接接收板 D2 槽，两颗 LED 分别插在转接板输出端。接线图已更新为 D2，沿用现有实车固件。**

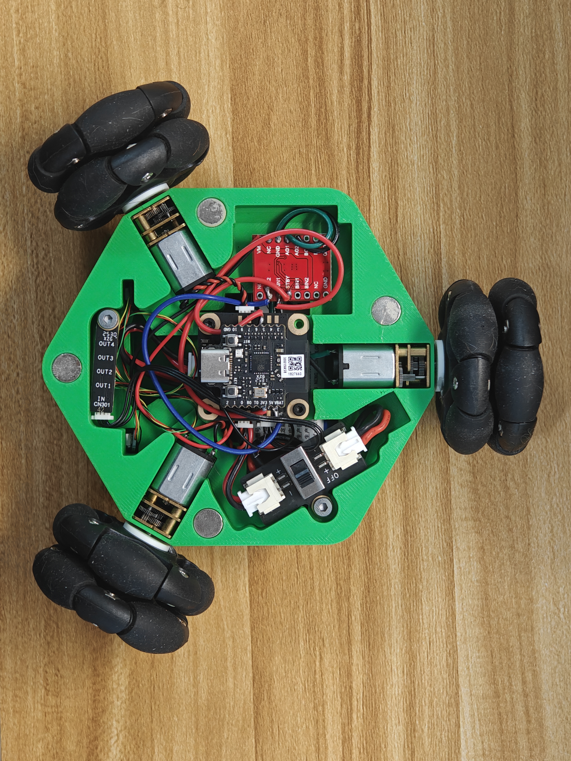
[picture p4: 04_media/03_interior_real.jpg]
内部接线实拍


作者最新图采用 **M1 = 右前、M2 = 左前、M3 = 后轮** 的标注。App 内的逻辑轮位可能与物理端口名不同，复刻时用标定向导把实际端口映射到对应轮位，不要仅凭 M1/M2 的名称判断左右。

| 连接关系 | 用途 |
|---|---|
| 接收板 M1 → 图示右前电机 | 板载第一路电机输出 |
| 接收板 M2 → 图示左前电机 | 板载第二路电机输出 |
| GPIO21 → 外接板 AIN1，GPIO20 → AIN2 | 配套主固件的第三电机控制输入 |
| 外接板 AO1 / AO2 → M3 后轮电机两焊片 | 第三电机输出；方向通过标定确认 |
| 开关串在电池与接收板供电之间 | 整车主电源控制 |
| 电机电源 → 驱动板 VM；各模块 GND 共地 | 驱动供电和信号参考 |
| 灯转接板 OUT → 两颗 RGB LED | 两盏前灯输出 |
| **接收板 D2 槽 → 灯转接板 IN** | 按作者实车确认的接法，沿用现有固件；灯供电和地线按模块实际针序连接 |

**驱动板针脚需要与购买的实际模块核对：**

- 红板素材带有 `PWMA / PWMB / VCC` 丝印，而先前实车照片相应位置为 `NC`。不能把图上同一位置的焊盘名称直接当成任意 DRV8833 模块的定义，尤其要核对 **VM、电源地、休眠/使能端**；图中未明确的 VM 供电还需补齐。

DRV8833 芯片采用双 H 桥和 `nSLEEP` 休眠控制，具体模块可能采用不同引出名称或板载接法；不能把 `STBY` 当成所有模块都通用的引脚定义。芯片定义可查 [TI 官方 DRV8833 页面及数据手册](https://www.ti.com/product/DRV8833)。

电池标称 7.4 V 不等于电机得到 6 V，也不等于灯模块需要的电压；按实车供电方案核对各输出。首次通电前检查极性、共地、焊点和供电，再架空运行单轮测试。

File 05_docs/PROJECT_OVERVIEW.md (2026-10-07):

# 项目总览

RokiCar：三轮全向、六边形车身、可打印外壳与可拆卸磁吸顶盖。当前机械为 V8：取消两颗定位销，顶盖仅一组磁吸，横向公差每侧 0.40 mm，围边厚 1.60 mm；内部安装结构、三轮机构和原底壳不变。顶盖、车壳顶部各一颗 Ø8×2 磁铁；底壳另四组，整车共十颗。

手机端保持 Android 1.22.0。主固件保持现有控制逻辑，仅调整标准启动方式。最新 D2 灯接法经作者确认。仓库公开，下载见最新 Release。

当前建模检查、固件本地检查与既有 APK 下载校验不等于重新进行实物打印或刷写。复刻流程、物料与最新图片见 README 和 PDF。

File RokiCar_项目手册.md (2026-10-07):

# RokiCar｜把三只轮子，玩成更多方向

资料更新：2026-10-08。外壳与顶盖按 **RokiCar V8** 整理，软件仍使用 Android 1.22.0 与配套实车固件。

**一台可以横着走、原地转，也可以带着相机换个视角看世界的三轮全向小车。**

RokiCar 主封面

普通小车要先转弯再换方向，RokiCar 可以直接向侧面平移。三只全向轮配合独立电机控制，让前进、后退、横移和原地旋转出现在同一个小底盘上。装好它，你可以先拿手机玩起来，再慢慢研究它为什么能这样移动。

绿色六边形车身、黑色全向轮和两盏前灯，是 RokiCar 的样子；可打印外壳、可修改的模型、手机 App 和 MicroPython 程序，则是继续改造它的入口。你可以复刻一台，也可以把它做成自己的版本。

## 为什么值得做一台

- **移动方式有意思。** 前后左右平移、斜向移动与原地旋转，不需要机械转向机构。
- **手机就是控制器。** 当前提供 Android App，通过小车自己的 Wi-Fi 热点控制，基础操控不依赖互联网或云端账号。
- **普通 FDM 就能参与。** 车壳、顶盖和底壳按发布模型打印；颜色可以自由搭配。
- **买起来有两条路。** 想省事可以选 CyberBrick 全能套件；已有配件或希望控制预算，可以按清单分开购买。
- **做完还有得玩。** 能调轮速、改灯色、研究三轮运动学，也能尝试轻型相机搭载、专用顶盖或自己的控制逻辑。

外接驱动板、三台电机和三只轮子的参考费用合计约 **35.5 元**。这是三项外购物料的合计，**不是整车总价**；CyberBrick、电池、联轴器、磁铁、打印耗材和线材另计。

## 目前有哪些功能

以下按资料包内 **RokiCar Android 1.22.0 + 配套主固件** 整理；历史版本介绍中的旧功能不作为当前承诺。

| 功能 | 能做什么 | 使用说明 |
|---|---|---|
| 三轮全向混控 | 前进、后退、左右横移、斜向移动、原地旋转 | 先完成轮位与方向校准 |
| 手机摇杆控制 | 单摇杆、双控制、速度档位、旋转控制 | Android App 操作 |
| 横屏双手驾驶 | 两个摇杆配合控制，左右分区原地旋转 | 适合双拇指操控 |
| 手机姿态控制 | 通过倾斜手机控制移动 | 依赖手机传感器；手机航向跟随属于开环估算 |
| 电机标定 | 识别端口与轮位、修正正反转、设置最低稳定 PWM、调整轮速增益 | 先架空三轮再标定；可以保存配置 |
| RGB 灯光 | 开关、颜色与亮度调整，两盏前灯同步变化 | 需按当前灯控针脚连接 |
| 停车逻辑 | 急停；横屏按住运动、松手停车；退出或后台时发送停车；固件运动命令超时停车 | 当前固件命令超时阈值为 500 ms，首次装配需确认实际动作 |
| Wi-Fi 信号查看 | RSSI 实时曲线、数据年龄等信息 | 实际更新速度取决于手机 Wi-Fi 驱动 |
| 配置保存与查询 | 保存电机映射、方向与校准设置，查询灯光状态 | 固件与 App 需要配套 |
| 模型改造与学习 | STEP 模型、打印零件、运动学教程和模拟器 | 适合改外壳、做配件、学习混控 |

### 实验功能

**轨迹反放与 RSSI 辅助返航：** App 记录控制轨迹，再以反向顺序回放，并尝试结合 Wi-Fi 信号变化作局部修正。没有编码器或定位闭环，轮子打滑、地面差异和信号波动都会产生误差。这是一项可参与改进的实验功能，不能等同于可靠的自主返航。

**手机航向跟随：** 使用手机方位和虚拟车头估算控制转向；车体没有独立航向反馈，不能视为真正的无头模式或车载陀螺仪闭环。

当前 App 的 **AI 页面为待开发状态**。旧文档里的语音、云端 AI 和方形路径按钮不列为当前可用功能。摄像头图传、云台控制、视觉避障和自主导航也不属于基础版本。

## 买什么：省事买套件，省钱按需买

### 路线 A：CyberBrick 全能套件

适合第一次接触 CyberBrick、希望少配接口和线材的朋友。先核对所选套件是否含核心板、接收板、开关、灯转接板、LED 与对应线缆；套件内容和不同销售版本可能有差异。

仍需对照本项目补齐 **DRV8833、3 台指定规格 N20 电机、3 只 47 mm 全向轮及适配联轴器**。套件内已有且规格吻合的配件不用重复购买。套件里的其他配件可以留给后续项目。

### 路线 B：按需单独购买

核心组合是 **CyberBrick 核心板 + 接收板 + 单块 DRV8833**。接收板驱动两台电机，外接 DRV8833 驱动第三台；手机 Wi-Fi 操控不要求额外购买遥控发射板。

| 物料 | 数量 | 选择要点 | 参考费用 |
|---|---:|---|---:|
| CyberBrick 多功能核心板 | 1 | 与接收板配套，运行项目 MicroPython 固件 | 按购买渠道 |
| CyberBrick 接收板 | 1 | 带 M1/M2 电机输出；不要买成遥控发射板 | 按购买渠道 |
| **DRV8833 驱动板** | **1** | 用 A 路驱动第三电机；同商品页里要选 DRV8833 型号 | **约 4 元** |
| **GA12-N20 减速电机** | **3** | **6 V、200 转/分钟**；核对轴形、轴长、安装包络 | **约 8 元/台，合计 24 元** |
| **47 mm 全向轮** | **3** | 与底盘及电机轴匹配；所给链接注明不带联轴器 | **约 2.5 元/只，合计 7.5 元** |
| 联轴器 / 轮毂连接件 | 3 | 一端匹配电机轴，另一端匹配轮子；配套螺钉也需备齐 | 另计 |
| 电源开关模块 | 1 | 匹配接收板电源接口和电池插头 | 按购买渠道 |
| LED 转接板 / 灯分线板 | 1 | 当前资料使用 CN301 一类 WS2812 转接板，核对线序 | 按购买渠道 |
| 单颗 RGB LED 灯模块 | 2 | 两盏前灯；可按颗购买，需要对应线缆 | 按购买渠道 |
| 电池组 | 1 | 模型参考为 14500 电芯组成的 7.4 V、800 mAh 电池组；按实际尺寸与接口匹配 | 另计 |
| 电池对应充电器 | 1 | 与电池串数和充电接口匹配；已有匹配充电器可复用 | 另计 |
| 电机/灯光供电处理模块 | 按实车方案 | 6 V 电机、灯模块电源与电池电压分别核对；具体实车模块型号待补 | 另计 |
| 顶盖磁铁 | **共 2 颗** | **Ø8×2 mm 圆片钕铁硼磁铁**，沿厚度方向充磁；顶盖 1 颗、车壳 1 颗，只有一组磁吸位置 | 另计 |
| 底壳磁铁 | **共 8 颗** | 同规格 **Ø8×2 mm**；底壳 4 颗、车壳底部 4 颗，形成四组磁吸固定；整车磁铁合计 **10 颗** | 另计 |
| N20 电机固定螺丝 | **6 颗** | **M1.6×3 mm 机牙螺丝**，每台电机 2 颗；作者已确认 | 另计 |
| 模块固定自攻螺丝（较大孔） | 建议备 4 颗 | **BT3×6 mm**，对应模型中两处 Ø2.4 mm 塑料底孔；建议规格，需核对被夹件厚度 | 另计 |
| 电子板固定自攻螺丝 | 建议备 10 颗 | **BT2.3×4 mm**，用于模型中 Ø2.0 mm 的塑料底孔；浅孔需配垫片控制旋入深度 | 另计 |
| 绝缘平垫片 / 垫圈 | 按孔位配备 | 配合电子板自攻螺丝，避免螺钉顶到盲孔底；厚度按实际板厚选取 | 另计 |
| 连接线、插头、热缩管 | 按装配需求 | 接收板、电机、灯和开关的接口规格可能不同 | 另计 |
| FDM 打印件 | 车壳、顶盖、底壳各 1 | 绿色车壳可搭配白色或深色底壳 | 按耗材用量 |
| 相机及固定配件 | 可选 | 用于拓展展示，不计入基础 BOM | 自备 |

**采购参考价格由作者提供，整理日期为 2026-10-07；不含运费，以下链接商品规格及价格以购买时的选项为准。** 三台电机建议使用相同电压和转速规格，仍需通过 App 校准实际轮速。

### 作者提供的采购链接

1. [GA12-N20 直流减速电机](https://e.tb.cn/h.jZcV4WeUt8d2Sem?tk=MxeITKCtN0T)：选 **6 V / 200 rpm**。搜索关键词：`GA12-N20 6V 200转 减速电机`。
2. [TB6612FNG / DRV8833 电机驱动模块](https://e.tb.cn/h.jZc3rSfxJGTOzlx?tk=jM0xTKCHP70)：选 **DRV8833**。两个型号的电源和控制针脚不能混用。搜索关键词：`DRV8833 电机驱动模块`。
3. [47 mm 橡胶全向轮](https://e.tb.cn/h.8ANl6D2rXDkaOyK?tk=3iwCTKBqVp7)：购买 **3 只**，另配匹配联轴器。搜索关键词：`47mm 机器人 全向轮 不带联轴器`。

短链接可能需要淘宝 App 打开，失效时可按商品名搜索。本次未能直接读取淘宝商品详情，以上价格和规格按作者提供的信息整理。

### 螺丝与磁铁：按位置选，不要全部买成同一种

**电机固定：M1.6×3 mm，共 6 颗。** 每台 N20 使用 2 颗，拧入电机金属安装螺纹。这一处使用机牙螺丝；其余拧入打印件的固定位置采用自攻螺丝。选择不与轮组、外壳干涉的低头或盘头，不建议自行换成长螺丝。

**塑料件固定建议先准备 BT3×6 mm 和 BT2.3×4 mm 两种。** 尺寸表示螺纹外径 × 螺杆长度，盘头或圆柱头的长度按头部下方量取；不要把机牙 M3 当成 BT3 自攻螺丝购买。内六角或十字槽按所购螺丝配工具，优先选择头部能平稳压住安装孔、又不会接触元件的款式。BT3×6 可参考 [Bambu Lab 官方 BT3 自攻螺丝规格](https://asia.store.bambulab.com/products/bt3-socket-head-cap-self-tapping-screws-shcs-new)。

上表的两种 BT 型号是依据 CAD 孔径给出的**采购与试配建议，尚未实装确认**；备货数量包含余量，不是整车已经核实的消耗数量。模型中有两处 Ø2.4 mm、深约 7.5～8 mm 的孔，以及四处 Ø2.0 mm 安装孔，其中三处只有约 2 mm 深：

- Ø2.4 mm 底孔可先试 BT3×6；装配后的有效旋入长度约 4～5 mm 较合适，实际取决于被固定零件的厚度。
- Ø2.0 mm 浅孔可先试 BT2.3×4。**螺杆伸入打印件的长度应控制在约 1.5～1.7 mm**，为孔底留余量；按板厚增加绝缘平垫片。例如用 4 mm 螺丝时，被夹板和垫片总厚度应约为 2.3～2.5 mm。未达到这个厚度时不能直接拧到底，也不要改用 6～8 mm 长螺丝。
- 手动轻拧至固定即可；首次试配先确认头径、旋入阻力和孔底余量。底壳及其他位置按实际固定方式选用，这两份模型不足以确定所有位置的螺丝数量和长度。

搜索关键词：`M1.6×3 机牙螺丝`、`BT3×6 塑料自攻螺丝`、`BT2.3×4 塑料自攻螺丝`、`8×2 圆片钕铁硼磁铁 轴向充磁`。若店铺没有短规格，不要直接用更长规格替代。

**磁铁统一准备 Ø8×2 mm 圆片钕铁硼磁铁，共 10 颗：**

- **V8 顶盖一组：2 颗。** 顶盖 1 颗、车壳顶部 1 颗；孔为 Ø8.40 mm、深 2.10 mm。
- **原底壳四组：8 颗。** 底壳 4 颗、车壳底部 4 颗；原模型凹槽为 Ø8.20 mm、深 2.30 mm，孔位已在两件模型间对应。

每组相对面应相吸，四组底壳磁铁尤其要逐个标记极性。先试配，再少量胶粘固定，避免胶溢到配合面；底壳孔深余量较大，磁铁位置与胶层按实际装配调整。顶盖只有一组磁吸位置，没有重新增加第二组。

## 打印与装配

当前车壳与顶盖制造资料为 **V8**：`01_shell_print.stl` 车壳、`02_hatch_print.stl` 顶盖、`04_magnet_fit_coupon.stl` 磁铁孔试配块。原底壳沿用原模型，提供 STEP；若从零复刻，需一并准备底壳打印件，不能只下载顶盖和车壳。

V8 已取消两颗定位销，盖子与围边每侧留 **0.40 mm** 横向间隙，围边厚 **1.60 mm**，只保留一组磁吸位置。内部安装结构和三轮机构保持原设计。

普通 FDM 可以作为制作方式。**0.4 mm 喷嘴、0.2 mm 层高、3～4 圈外壁**可作为切片起始设置。内部桥接、支撑和孔位配合仍需在切片软件中确认；磁铁试配块可以先小量试打。顶盖 STL 已按外顶面朝下摆放，切片时核对朝向。

1. 打印并检查车壳、底壳与顶盖，确认孔位和磁铁配合；底壳四组磁铁逐对确认相吸后固定。
2. 使用 6 颗 M1.6×3 mm 螺丝固定三台电机，再装入联轴器和轮子，检查轮组完整转动，轮子不擦车壳。
3. 按实际安装孔选择短自攻螺丝固定核心板、接收板、驱动板、开关和灯模块；浅孔核对垫片厚度与旋入长度，然后整理线束。
4. 连接电池，电池线从内部走线，保持顶盖安装面无夹线。
5. 顶盖和车壳各装 1 颗 Ø8×2 mm 磁铁，固定前确认这一对极性相吸；轻放顶盖，确认贴合与取盖手感。
6. 架空三轮刷机和标定，最后低速落地试跑。

不同模型版本的磁铁孔位可能不同。旧 V7 顶盖为两组、共四颗磁铁；本篇按 V8 顶盖的一组、共两颗，加原底壳的四组、共八颗整理，整车合计十颗，不能混用旧顶盖。若改用其他底壳，重新按对应孔位统计。

## 接线：两台接接收板，第三台接 DRV8833

作者重新整理的接线图

**灯光连接：LED 转接板的 IN 接接收板 D2 槽，两颗 LED 分别插在转接板输出端。接线图已更新为 D2，沿用现有实车固件。**

内部接线实拍

作者最新图采用 **M1 = 右前、M2 = 左前、M3 = 后轮** 的标注。App 内的逻辑轮位可能与物理端口名不同，复刻时用标定向导把实际端口映射到对应轮位，不要仅凭 M1/M2 的名称判断左右。

| 连接关系 | 用途 |
|---|---|
| 接收板 M1 → 图示右前电机 | 板载第一路电机输出 |
| 接收板 M2 → 图示左前电机 | 板载第二路电机输出 |
| GPIO21 → 外接板 AIN1，GPIO20 → AIN2 | 配套主固件的第三电机控制输入 |
| 外接板 AO1 / AO2 → M3 后轮电机两焊片 | 第三电机输出；方向通过标定确认 |
| 开关串在电池与接收板供电之间 | 整车主电源控制 |
| 电机电源 → 驱动板 VM；各模块 GND 共地 | 驱动供电和信号参考 |
| 灯转接板 OUT → 两颗 RGB LED | 两盏前灯输出 |
| **接收板 D2 槽 → 灯转接板 IN** | 按作者实车确认的接法，沿用现有固件；灯供电和地线按模块实际针序连接 |

**驱动板针脚需要与购买的实际模块核对：**

- 红板素材带有 `PWMA / PWMB / VCC` 丝印，而先前实车照片相应位置为 `NC`。不能把图上同一位置的焊盘名称直接当成任意 DRV8833 模块的定义，尤其要核对 **VM、电源地、休眠/使能端**；图中未明确的 VM 供电还需补齐。

DRV8833 芯片采用双 H 桥和 `nSLEEP` 休眠控制，具体模块可能采用不同引出名称或板载接法；不能把 `STBY` 当成所有模块都通用的引脚定义。芯片定义可查 [TI 官方 DRV8833 页面及数据手册](https://www.ti.com/product/DRV8833)。

电池标称 7.4 V 不等于电机得到 6 V，也不等于灯模块需要的电压；按实车供电方案核对各输出。首次通电前检查极性、共地、焊点和供电，再架空运行单轮测试。

## 从组装到第一次开动

1. 使用配套 `boot.py`、`main.py`、`rokicar_core.py` 刷入 CyberBrick 核心板。保留发布包中的文件名，不要混用旧版本程序。
2. Android 手机安装 **RokiCar-Controller-v1.22-debug.apk**。当前没有交付原生 iOS App。
3. 开启小车，连接热点 **`RokiCar`**，默认密码 **`12345678`**。控制连接地址为 **`ws://192.168.4.1/ws`**。
4. 在设置与校准中逐个测试 M1、M2、外接驱动，确认轮位和正反转，再校准最低稳定 PWM 与速度增益并保存。
5. 架空预览前进、横移和原地旋转，确认松手、急停及断连停车动作。
6. 落地低速试跑。若横移歪斜，先检查轮位、轮向和轮速差，不要直接用提高速度掩盖问题。

手机可能提示该 Wi-Fi 没有互联网，这是本地控制热点的正常情况。连接期间保持手机使用这个网络；基础控制不需要额外 AI Key。

## 给顶部更多可能

相机搭载实拍优化

实拍中已经展示了搭载小型相机的形态。它可以成为移动拍摄底盘，也可以成为研究相机支架、传感器与扩展顶盖的起点。

可拆卸顶盖适合作为独立改件：先在 STEP 副本上设计安装孔、转接支架或加强筋，确认不会碰到电池与内部线束，再打印专用盖子。相机属于额外配件，照片中的相机不在基础采购清单里；当前 App 未集成图传或云台控制，也尚未交付已验证的磁吸相机支架。

想做机械扩展，可以尝试轻型相机底座、可替换饰板或传感器盖；想做软件扩展，可以尝试编码器反馈、车载 IMU、闭环轮速、定位与视觉处理。相机固定、重心变化和顶盖承载应在自己的配件方案中实测。

## 欢迎把它变成你的 RokiCar

你可以从一台能玩的车开始：换一个颜色，拍一段横移视频，或者做一块自己的顶盖。进一步也可以优化灯光效果、改手机交互、完善接线教程，或让实验返航变得更可靠。

后续值得一起做的方向：

- 收集不同打印机、材料与磁铁的配合经验。
- 完善采购型号、插头针序、供电模块和逐针接线图。
- 做轻量、牢固、可重复拆装的相机扩展盖。
- 增加编码器或车载 IMU，改善轮速一致性与航向反馈。
- 研究图传、视觉功能和有定位反馈的导航。
- 改进 Android 兼容性，探索其他客户端。

如果你完成了复刻，欢迎展示你的版本，并附上打印材料、电机规格、软件版本和遇到的问题。能让下一位少走一步弯路的反馈，就已经很有价值。

## 刷写与下载

优先按 [AI 刷写说明](05_docs/交给AI刷写.txt) 操作，完整步骤见 [用户刷写教程](05_docs/用户刷写教程.md)；简明入口见 [复刻 PDF](05_docs/RokiCar_复刻指南.pdf)。下载使用 [最新 Release](https://github.com/yinbaozong/RokiCar/releases/latest)，不要从旧 V7 Release 获取当前外壳。

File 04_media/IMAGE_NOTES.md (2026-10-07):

# 图片说明

01_hero_real.png：基于实拍补盖并按作者顶盖参考修正；02_camera_real.png：基于实际搭载相机的照片优化。两张为实拍修图，不作为毫米级 CAD 尺寸依据，也不表示图传、云台或专用磁吸相机支架已完成。

03_interior_real.jpg、04_bottom_real.jpg 为原始实拍。相机另购。最新模型预览见 ../01_model/images。history/04_exploded_cad.png 是旧 V7 爆炸图，不作 V8 结构展示。

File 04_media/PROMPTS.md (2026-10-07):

生成方式：内置 imagegen 图片编辑。

主封面提示词：
Use case: precise-object-edit / lighting-weather. Asset: MakerWorld cover photograph for RokiCar.
Input 1 is the EDIT TARGET: real wooden-floor front three-quarter photograph of the green three-wheel car with an exposed blue battery. Input 2 is SUPPORTING GEOMETRY REFERENCE ONLY for the low polygonal battery cover; do not use its rendered vehicle, wheels, lighting, or background.
Edit the real photograph. Preserve the actual car's body shape, proportions, white bottom plate, exact three black omni-wheel assemblies, small visible screws, and the two white front lamp windows. Preserve camera perspective and natural contact shadows. Preserve real FDM surface grain, rubber texture and slight physical imperfections. Do not convert into a 3D render or glossy idealized toy.
Required repair: conceal the open blue battery with a slim GREEN removable cover matching the reference's chamfered polygon language, aligned to the photographed roof plane and centered over the actual battery opening. Keep it low, closely seated with a narrow realistic seam, same green printed-plastic texture. No dome, no tower, no large protruding handles, no camera. Only add the missing cover; do not reshape roof or chassis. Cover must fit photographed scale and perspective.
Photographic optimization: neutralize excessive yellow cast, brighten subject naturally, improve wheel visibility while keeping black rubber dark, remove distracting hairs/dust conservatively, gentle sharpness and soft daylight. Keep a believable warm wooden floor with subtle soft background defocus; no futuristic stage, green smoke, metallic reflections, fake speed effects, or studio CGI.
Composition: landscape 4:3 cover, full vehicle and every wheel within frame with generous safe margins, subject dominant but not cramped. Clean available negative space near upper left. Add ONLY the title "RokiCar" in restrained dark charcoal bold sans-serif in that space. No other text, fake badges, logos, watermarks, price claims, or specifications. End result should read as a polished hobbyist's real product photograph.

相机封面提示词：
Use case: lighting-weather / precise-object-edit. Asset: second MakerWorld cover showing optional camera payload for RokiCar.
The attached image is a REAL PHOTO to edit, not a design reference. Keep the actual green three-wheel robot and the real black camera already standing on its roof. Lock the exact body geometry, white bottom edge, three-wheel structure, screws, two glowing lamp positions, camera size, lens size, existing camera logo and camera position. Do not invent a mounting bracket or claim magnetic mounting. Do not substitute a smaller camera, alter symmetry, change to another robot, add accessories, or create a CGI render.
Improve the photographic exposure: brighten the black camera enough to show its actual plastic texture and lens; balanced daylight color, clean green printed plastic, believable FDM grain, realistic dark rubber with detail. Preserve slight real-life imperfections. Reduce harsh lamp bloom so the two cyan-green lights are visible and realistic; subtle floor reflections only as already photographed.
Keep a warm wooden surface, soften the background, and remove the distracting door/skirting geometry by making the background a simple gently blurred continuation of the same real interior floor. Natural shadows remain under the wheels. No smoke, lasers, shiny futuristic set, dramatic fake light beams or artificial metallic surfaces.
Compose a landscape 4:3 photograph, full camera and complete car visible with breathing room around every wheel. Optical proportions must remain like the real photo, not compressed or cramped. Add ONLY "RokiCar" as restrained charcoal sans-serif title in empty space at upper left. Do not add claims about FPV, AI, gimbal, autonomous driving or prices. This is an enhanced real DIY photograph demonstrating an optional camera payload, not an invented product render.

Precisely edit IMAGE 1, the RokiCar real-photo-based cover on wooden floor. IMAGE 2 is the user's correct CAD lid reference. Change ONLY the battery lid and its immediate mating rim to match the exact geometry in IMAGE 2: a broad low raised polygonal lid, with a long straight front-center edge, short diagonal corner edges and long angled side edges, matching the six-sided body's orientation; a visible shallow vertical peripheral skirt under the lid, thin upper edge bevel, narrow seam, and the small recessed fingernail access on the right side as shown in reference. The lid is NOT a nearly flush inset plate: it sits slightly proud on its shallow skirt, with the same relative lid footprint and rim thickness seen in reference. Transfer that lid geometry into the photograph's existing perspective, accounting for its different view direction; do not simply paste the CAD screenshot. Keep green printed-plastic texture and realistic FDM layers, daylight shading and close physical fit. Preserve EVERYTHING else in IMAGE 1: car body proportions, all actual black omni-wheel assemblies and screws, two white lamp windows, white bottom plate, wooden floor, title RokiCar, camera angle, composition and lighting. Do not swap the car for a render, change wheels, darken bottom plate, create protruding handles, add a camera or redesign the car. Only repair the lid shape, shallow skirt, seam and right-side access to match reference. Output same landscape cover composition and photographic style.

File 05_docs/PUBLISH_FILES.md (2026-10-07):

# 发布文件清单

仓库现为公开；从最新 Release 下载完整资料，或分开取模型、固件、APK 和 PDF。旧 v0.7.0 为历史 V7 发布，不作为当前外壳下载入口。

- 制造：01_model/cad（V8 车壳、顶盖与原底壳），01_model/print（STL 和磁铁试配块）。
- 源模型与检查：01_model/source、reference、docs；原整车参考装配仍含旧车壳。
- 固件：02_software/firmware/cyberbrick_rokicar_m1m2_plus_drv8833，三份 py 一起上传。
- 手机软件：02_software/android_apk/RokiCar-Controller-v1.22-debug.apk。
- 接线：03_hardware_and_learning/RokiCar接线图_D2.png；其他旧接线资料标为历史参考。
- 图片：04_media/01_hero_real.png、02_camera_real.png、03_interior_real.jpg、04_bottom_real.jpg。
- 指南：05_docs/RokiCar_复刻指南.pdf；AI 优先、手动备用。
- MakerWorld 正文：05_docs/MAKERWORLD_DESCRIPTION.md。

旧 V7 爆炸图与取盖剖面归入 history，仅作旧版记录，不代表 V8。已移除旧相机/云台概念宣传图。

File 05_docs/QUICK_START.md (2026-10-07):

# 快速开始

1. 优先阅读 [复刻指南 PDF](RokiCar_复刻指南.pdf) 与 [物料清单](BOM.md)。
2. 下载 V8 车壳、顶盖和原底壳；Ø8×2 mm 磁铁整车 10 颗（顶盖一组 2 颗，底壳四组 8 颗），电机 M1.6×3 螺丝 6 颗。
3. 先试配磁铁孔，再打印装配。无定位销，顶盖间隙每侧 0.40 mm，围边厚 1.60 mm。
4. 按 [D2 接线图](../03_hardware_and_learning/RokiCar接线图_D2.png) 接线，M1 右前、M2 左前、M3 后轮。灯转接板 IN 接 D2，作者已确认正常，保持现有固件定义。
5. 优先将三文件固件交给可访问本机串口的 AI，附上 [提示词](交给AI刷写.txt)；手动方式见 [刷写教程](用户刷写教程.md)。不擦除 Flash，保留校准 JSON。
6. 安装 Android 1.22.0 APK，连接热点 RokiCar / 12345678，控制地址 ws://192.168.4.1/ws。
7. 架空校准轮位、正反转、最低稳定 PWM 和增益；确认松手、急停和断连停车，再低速落地。

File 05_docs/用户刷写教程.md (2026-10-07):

# RokiCar 用户刷写教程（三文件版）

本教程对应本仓库主固件目录 中的 `boot.py`、`main.py`、`rokicar_core.py`。请使用这三个文件，暂不采用之前的单文件版。车灯接法已由作者确认可用，保持现有程序和 D2 接线。

## 先分清两件事

这里的“刷固件”是把三份 Python 程序写进核心板的文件系统；不是用烧录器写入 `.bin` 镜像。核心板必须已有兼容的 MicroPython 环境，能够通过 USB 串口进入 REPL。不要为了上传这三份文件擦除 Flash，也不要随意给 CyberBrick 刷通用 ESP32 固件。

本包的 `boot.py` 已改为有限初始化；正常启动时由 MicroPython 自动执行 `main.py`。这是为了方便以后连接工具和更新程序，电机控制、灯光、协议和 Wi-Fi 参数未改。依据：[MicroPython 官方启动说明](https://docs.micropython.org/en/v1.26.0/reference/reset_boot.html)。

## 准备什么、安装什么

- CyberBrick 核心板、一根支持数据传输的 USB 线、电脑和本资料包。
- 初学者推荐 **Thonny**：[官网下载](https://thonny.org/)。Windows 常规安装版自带电脑端 Python，按下面的图形界面流程操作即可，不必另装 VS Code、Arduino IDE 或 esptool。
- 用命令行或让能控制本机的 AI 帮忙时，安装 [Python 3](https://www.python.org/downloads/windows/)，再安装官方 `mpremote` 工具。
- Windows 如果没有识别出串口，先换数据线/USB 口，再按设备硬件 ID 找对应官方驱动；不默认要求每块板安装 CH340/CP210x 驱动。
- 刷写和校准时架空三轮；更稳妥的文件上传阶段可以先断开电机电源，保留核心板 USB 供电。

## 方式一：Thonny 图形界面

1. 接好 USB，关闭占用该串口的其他工具。安装并打开 Thonny。
2. 在解释器设置中选择适合板子的 MicroPython（ESP32）解释器，并选择实际 USB 串口。不同 Thonny 版本菜单位置可能稍有不同。不要点击“安装/更新 MicroPython”替换底层固件。
3. 点击停止，必要时在 Shell 按 `Ctrl+C`，直到出现 `>>>`。输入 `import sys; print(sys.implementation)`，应能确认 MicroPython。不能进入 REPL 时，先处理连接问题，不继续覆盖文件。
4. 打开“文件”视图，将设备上已有的 `boot.py`、`main.py`、`rokicar_core.py`、`rokicar_config.json` 下载到电脑的备份文件夹；没有的文件可以略过。保留其他原厂文件。
5. 将本包的 `boot.py` 保存到设备根目录，随后保存 `rokicar_core.py` 和 `main.py`。三个文件名必须准确，不要变成 `main.py.txt`，也不要只复制外层 `01_固件` 文件夹。设备文件系统的显示路径可能是 `/` 或 `/flash`，应放到已有启动文件所在的根目录。
6. 如果旧程序的看门狗导致反复重启，不要在持续断连状态下继续上传。先重新连接并尝试中断；仍不稳定时按该板官方恢复流程恢复可用 REPL，再上传。不要自行猜测烧录偏移或擦除指令。
7. 上传完成后，重新从设备下载这三份文件到另一个文件夹，与本地原文件比较内容或 SHA-256。只看到“保存成功”还不够。
8. 关闭串口连接，按复位键或断电重启。搜索热点 `RokiCar`，密码 `12345678`；Android App 连接地址为 `ws://192.168.4.1/ws`。

## 方式二：命令行 / AI 操作

在 Windows PowerShell 中，先安装工具并找串口。下例 `COM5` 仅是示例，必须换成实际端口：

```powershell
py -m pip install --upgrade mpremote
py -m mpremote connect list
py -m mpremote connect COM5 resume exec "import sys; print(sys.implementation)"
py -m mpremote connect COM5 resume fs ls
```

进入本仓库主固件目录 文件夹后操作。先建立电脑备份目录，再逐份下载设备上已有文件；不存在的文件记录为“不存在”，不能把串口连接错误也当成“文件不存在”：

```powershell
New-Item -ItemType Directory -Path .\backup -Force
py -m mpremote connect COM5 resume fs cp :boot.py .\backup\boot.py
py -m mpremote connect COM5 resume fs cp :main.py .\backup\main.py
py -m mpremote connect COM5 resume fs cp :rokicar_core.py .\backup\rokicar_core.py
py -m mpremote connect COM5 resume fs cp :rokicar_config.json .\backup\rokicar_config.json
```

确认连接稳定、备份已完成，再上传。保留原校准 JSON，不用默认参数覆盖作者已有标定：

```powershell
py -m mpremote connect COM5 resume fs cp boot.py :boot.py
py -m mpremote connect COM5 soft-reset fs cp rokicar_core.py :rokicar_core.py + fs cp main.py :main.py
```

`soft-reset` 从 raw REPL 发起时不自动运行 `main.py`，便于传文件；旧版本工具的 `resume` 用于跳过自动软复位。工具和板子若在软复位后重新枚举 USB，需要重新查询端口再连接，不能坚持使用已消失的端口。命令格式可查 [官方 mpremote 文档](https://docs.micropython.org/en/latest/reference/mpremote.html)。

回读并比对，任何一项失败都不要宣称刷写完成：

```powershell
New-Item -ItemType Directory -Path .\readback -Force
py -m mpremote connect COM5 soft-reset fs cp :boot.py .\readback\boot.py + fs cp :main.py .\readback\main.py + fs cp :rokicar_core.py .\readback\rokicar_core.py
foreach ($name in @('boot.py','main.py','rokicar_core.py')) {
    $sourceHash = (Get-FileHash -LiteralPath (Join-Path . $name) -Algorithm SHA256).Hash
    $deviceHash = (Get-FileHash -LiteralPath (Join-Path .\readback $name) -Algorithm SHA256).Hash
    if ($sourceHash -ne $deviceHash) { throw "回读校验失败：$name" }
    Write-Host "一致：$name"
}
py -m mpremote connect COM5 resume reset
```

若上传中断，重新连接并上传失败的文件，保持三份文件来自同一版本。若需恢复，上传备份中的辅助文件、主程序及启动文件，再硬复位；原先不存在的文件与原厂恢复方法按备份记录处理，不随意删除整个文件系统。

## 怎样才算成功

- 三份程序在正确根目录，回读内容与本地逐份一致。
- 关闭上传工具后断电重启，能重新找到 `RokiCar` 热点，并能在 App 建立连接。
- 架空状态逐台测试电机，完成轮位、方向、最低稳定起转值与轮速增益校准，确认前进、横移和旋转正确。
- 验证松手停车、急停和连接中断后停车，再低速落地。

“文件写入成功”“程序启动成功”“实车动作正确”是三个不同验收步骤。文件比对不能替代实车验证。本次整理完成了本地语法、依赖及启动文件回归检查，未连接实车执行刷写。

## 常见问题

| 现象 | 怎么处理 |
|---|---|
| 没有 COM 端口 | 数据线、USB 口、设备管理器硬件 ID 与驱动逐项检查 |
| Access denied / 端口被占用 | 关闭 Thonny、串口监视器或另一个 AI 使用的进程，仅保留一个连接 |
| 提示找不到 `rokicar_core` | 核对辅助文件是否在设备根目录、文件名及回读内容 |
| 上传后不自动启动 | 硬复位；检查三份文件路径、标准启动文件及 Shell 错误信息 |
| 反复重启 / 看门狗报错 | 不继续盲写；恢复稳定 REPL，再检查旧启动器、供电与主程序报错 |
| 没有热点 | 先看串口报错，确认兼容 MicroPython 与供电，不先改引脚 |
| 电机轮位不对 | 架空三轮使用 App 标定，不靠换程序猜方向 |

## 可以直接交给 AI 的要求

把本包和旁边的 `交给AI刷写.txt` 一起交给具备本机终端及 USB 串口访问能力的 AI。纯聊天网页里的 AI 如果不能访问电脑和串口，只能指导操作，不能替你实际刷写。

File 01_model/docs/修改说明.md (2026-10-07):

# RokiCar V8｜取消定位销、单组磁吸与围边加厚

本版从 RIFT-V7 的原始车壳重建，原 V7 文件保留，输出在 `外壳设计/RokiCar-V8`。

## 本次修改

- 取消车壳两颗 Ø1.6 mm 定位销，顶盖对应的两处孔也取消。
- 顶盖只保留后侧 **一颗 Ø8×2 mm 磁铁**；车壳同一位置一颗配对。总共两颗磁铁、一个磁吸位置，前侧另一组孔不再生成。
- 围边改为 **1.6 mm 连续竖直壁**，高度为车顶以上 2.4 mm；保留取盖缺口。
- 取消原来的围边裁切方式，避免后侧斜边被原车顶轮廓裁成薄片。超出原车顶的少量围边用外侧斜面过渡支撑，过渡高度 3.2 mm、横向扩张 1.6 mm。
- 不移动内部安装结构、底壳或三轮机构。

## 配合尺寸

| 位置 | 设计尺寸 |
|---|---:|
| 盖子与围边横向间隙 | **每侧 0.40 mm**，相对两侧合计 0.80 mm |
| 模型中盖子底面与原车顶的轴向间隙 | 0.20 mm |
| 适配磁铁 | Ø8×2 mm |
| 车壳、顶盖磁铁孔 | **Ø8.40 mm × 深 2.10 mm** |
| 磁铁孔直径余量 | 0.40 mm，即径向每侧 0.20 mm |
| 磁铁孔深度余量 | 0.10 mm |
| 顶盖磁铁孔上方剩余材料 | 1.20 mm |
| 原车顶磁铁孔底及周边已核对的材料余量 | 至少 1.0 mm |

这些是用于普通 FDM 的设计余量，不是打印机的尺寸精度保证。磁铁孔按留胶间隙设计；先用试配块核对自己的磁铁与打印结果，不建议靠强行压入固定。

## 文件

- `cad/01_shell.step`：无定位销、单磁铁孔的新车壳。
- `cad/02_hatch.step`：无定位孔、单磁铁孔的顶盖。
- `cad/03_shell_assembly.step`：车壳与顶盖的装配位置参考。
- `print/01_shell_print.stl`：车壳打印文件。
- `print/02_hatch_print.stl`：顶盖打印文件，外顶面朝下。
- `print/04_magnet_fit_coupon.stl`：磁铁孔试配块。
- `docs/cad_checks.json`：几何核对数据。
- `docs/mesh_checks.json`：打印网格核对数据。

## 核对与下一步

已完成建模时的零件有效性、单实体、盖壳无实体重叠、电池取出路径、抠手通道、外侧过渡不侵入原内部、原车壳无非预期切除，以及多高度围边材料核对。打印网格检查另记于 `mesh_checks.json`。

尚未替你切片或实物试打。请优先查看你圈出的薄边能否形成连续路径，再确认盖子间隙和单组磁吸的手感。主发布文档与宣传封面仍为上一版，这次先交付修改模型供你确认。

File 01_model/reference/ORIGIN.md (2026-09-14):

# 输入与参照资产来源

- `original_shell.step`：用户提供的终版 `车体.STEP`，原始输入未修改；它是本次外观改型的建模依据。
- `render_context/original_0.stl`：用户提供装配体中的底壳。
- `render_context/original_1.stl`、`original_2.stl`、`original_3.stl`：用户提供装配体中的三个全向轮组。
- `render_context/original_14.stl`：用户提供装配体中的灯窗组件。

参照网格由用户提供的 `全部装配体.STEP` 提取，转换到原车壳坐标后仅用于展示。它们不是此次新设计的轮子、电子件或底盘，未核实各自第三方许可。正式公开这些文件前，由项目所有者确认再分发条件；可以单独移除 `render_context`，核心 CAD 建模仍可进行，但整车预览需要另行提供参照。

没有附带用户原项目的固件、APP、账号数据、个人配置或整个历史版本目录。

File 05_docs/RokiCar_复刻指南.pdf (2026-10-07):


RokiCar · 复刻指南 | 1

# RokiCar

# 三轮全向小车 · 从采购到开动的复刻指南

绿色六边形车身、三只全向轮与可拆卸磁吸顶盖

### 一台可以横着走、原地转，也可以带着小相机探索不同视角的小车。三台独立电机配合全向轮，不用转向机构 就能前后、左右和斜向移动。

## 做完能玩什么

### 手机 Wi-Fi 摇杆控制、横屏双手驾驶、手机倾斜控制、速度调节、电机标定、RGB 灯光与急停。基础操控不依

赖互联网。轨迹反放和 RSSI 辅助返航属于实验功能，不等同于闭环自主导航。

## 复刻路线

### 准备物料 → 打印外壳 → 安装电机与轮组 → 接线 → 交给本地 AI 上传三份程序 → 安装手机 App → 架空校准 → 低速落地。

相机不是基础套件必需品；基础版本没有集成图传、云台或视觉避障。

# 01 需要买哪些元器件

省事：选择 CyberBrick 全能套件，核对是否已含核心板、接收板、开关、灯转接板、LED 和线缆。省钱：按 下面清单单独购买；已有且规格吻合的配件不用重复买。

物料 | 数量 | 规格 / 选择要点 | 参考费用
CyberBrick 多功能核心 板 | 1 | 与接收板配套，运行项目 MicroPython 固件 | 按购买渠道
CyberBrick 接收板 | 1 | 带 M1/M2 电机输出；不要买成遥控发射板 | 按购买渠道
DRV8833 驱动板 | 1 | 用 A 路驱动第三电机；同商品页里要选 DRV8833 型号 | 约 4 元
GA12-N20 减速电机 | 3 | 6 V、200 转/分钟；核对轴形、轴长、安装包络 | 约 8 元/台，合 计 24 元
47 mm 全向轮 | 3 | 与底盘及电机轴匹配；所给链接注明不带联轴器 | 约 2.5 元/只， 合计 7.5 元
联轴器 / 轮毂连接件 | 3 | 一端匹配电机轴，另一端匹配轮子；配套螺钉也需备齐 | 另计
电源开关模块 | 1 | 匹配接收板电源接口和电池插头 | 按购买渠道
LED 转接板 / 灯分线板 | 1 | 当前资料使用 CN301 一类 WS2812 转接板，核对线序 | 按购买渠道
单颗 RGB LED 灯模块 | 2 | 两盏前灯；可按颗购买，需要对应线缆 | 按购买渠道
电池组 | 1 | 模型参考为 14500 电芯组成的 7.4 V、800 mAh 电池组；按实际 尺寸与接口匹配 | 另计
电池对应充电器 | 1 | 与电池串数和充电接口匹配；已有匹配充电器可复用 | 另计
电机/灯光供电处理模块 | 按实车方 案 | 6 V 电机、灯模块电源与电池电压分别核对；具体实车模块型号待 补 | 另计
顶盖磁铁 | 共 2 颗 | Ø8×2 mm 圆片钕铁硼磁铁，沿厚度方向充磁；顶盖 1 颗、车壳 1 颗，只有一组磁吸位置 | 另计
底壳磁铁 | 共 8 颗 | 同规格 Ø8×2 mm；底壳 4 颗、车壳底部 4 颗，形成四组磁吸固 定；整车磁铁合计 10 颗 | 另计
N20 电机固定螺丝 | 6 颗 | M1.6×3 mm 机牙螺丝，每台电机 2 颗；作者已确认 | 另计
模块固定自攻螺丝（较大 孔） | 建议备 4 颗 | BT3×6 mm，对应模型中两处 Ø2.4 mm 塑料底孔；建议规格， 需核对被夹件厚度 | 另计
电子板固定自攻螺丝 | 建议备 10 颗 | BT2.3×4 mm，用于模型中 Ø2.0 mm 的塑料底孔；浅孔需配垫 片控制旋入深度 | 另计
绝缘平垫片 / 垫圈 | 按孔位配 备 | 配合电子板自攻螺丝，避免螺钉顶到盲孔底；厚度按实际板厚选取 | 另计
连接线、插头、热缩管 | 按装配需 求 | 接收板、电机、灯和开关的接口规格可能不同 | 另计
FDM 打印件 | 车壳、顶 盖、底壳 各 1 | 绿色车壳可搭配白色或深色底壳 | 按耗材用量
相机及固定配件 | 可选 | 用于拓展展示，不计入基础 BOM | 自备

DRV8833、三台电机、三只轮子合计约 35.5 元，仅是这三项的参考价；不是整车总价。其余配件、运费和打印耗材另计。价格按作 者提供信息，购买时核对规格选项。

# 02 采购链接与紧固件

N20 电机：选择 6 V / 200 rpm，购买 3 台 https://e.tb.cn/h.jZcV4WeUt8d2Sem?tk=MxeITKCtN0T

驱动模块：选择 DRV8833，购买 1 块
https://e.tb.cn/h.jZc3rSfxJGTOzlx?tk=jM0xTKCHP70

### 47 mm 全向轮：购买 3 只，另配匹配联轴器

https://e.tb.cn/h.8ANl6D2rXDkaOyK?tk=3iwCTKBqVp7

淘宝短链接可能需要 App 打开。失效时搜索：GA12-N20 6V 200转；DRV8833 电机驱动模块；47mm 机器人全向轮。驱动商品页 同时列出 TB6612FNG 时，不要选错型号。

## 电机螺丝：M1.6×3 mm，共 6 颗

### 每台电机 2 颗，使用机牙螺丝拧入电机金属螺纹；不要把自攻螺丝拧进电机，也不要随意改用更长的螺丝。

## 打印件自攻螺丝：两种备选

建议先备 BT3×6 mm 4 颗、BT2.3×4 mm 10 颗。这是按模型孔径提出的试配采购建议，数量含余量，尚未实

### 装确认，不是核实后的全车消耗数量。

Ø2.4 mm 底孔可先试 BT3×6，有效旋入长度约 4～5 mm；Ø2.0 mm 安装孔中三处仅约 2 mm 深， BT2.3×4 应配合板厚和绝缘垫片，将伸入打印件的长度控制在约 1.5～1.7 mm。使用 4 mm 螺杆时，被夹板 与垫片合计厚度约 2.3～2.5 mm。

BT3 自攻螺丝参考规格
https://asia.store.bambulab.com/products/bt3-socket-head-cap-self-tapping-screws-shcs-new

## 磁铁：Ø8×2 mm 圆片钕铁硼，共 10 颗

沿厚度方向充磁。顶盖一组：盖子与车壳顶部各 1 颗，共 2 颗；底壳四组：底壳与车壳底部各 4 颗，共 8 颗。 顶盖只有一个磁吸位置。

顶盖磁铁孔 Ø8.40×深 2.10 mm；底壳配对孔 Ø8.20×深 2.30 mm。先确认每组极性相吸，试配后少量胶粘固定，避免胶进入配合面。

# 03 打印和机械装配

### 从作品附件下载模型，准备车壳、顶盖、底壳各一件。使用无定位销、单组顶盖磁吸的当前模型；不要只打印 顶盖和车壳而漏掉底壳。

## 普通 FDM 的起始设置

0.4 mm 喷嘴、0.2 mm 层高、3～4 圈外壁。按发布 STL 的摆放方向开始切片，顶盖外顶面朝下。检查桥接、

### 支撑和薄壁路径，先打印磁铁孔试配块。盖子与围边设计间隙为每侧 0.40 mm，实际配合仍由打印精度决定。


内部布局参考：先固定机械件，再装电路板并整理线束

### 1. 检查打印件、磁铁槽和轮组空间，清除毛刺；不要强行压入磁铁。

2. 用 6 颗 M1.6×3 固定三台 N20，装联轴器和全向轮，确认紧固且能完整转动，轮子不擦壳。

### 3. 固定核心板、接收板、外接驱动、开关和灯模块。按安装孔选择短自攻螺丝，浅孔用垫片限制旋入深度。

### 4. 电池放回原仓，线缆从内部走线；不在外部增加出线口，避免顶盖夹线。

5. 底壳四组、顶盖一组磁铁逐对确认相吸并固定，合上底壳和顶盖，确认可从抠手位取盖。

# 04 按图接线


M1 右前、M2 左前、M3 后轮；LED 转接板 IN 接 D2

连接 | 说明
接收板 M1 / M2 | 分别连接图示右前 / 左前电机
GPIO21 → AIN1；GPIO20 → AIN2 | 配套程序中的后轮控制输入；按实际模块针脚核对
DRV8833 AO1 / AO2 → M3 | 连接后轮电机两根线，正反转由 App 标定确认
灯转接板 IN → D2；OUT → 两颗 LED | 作者已确认此接法正常，沿用现有灯光程序
电池 → 开关 → 接收板供电 | 按模块正负极和接口针序连接
电机电源 → VM；各模块 GND 共地 | VM 供电需按实际电源方案补齐，不把图中遗漏当作无需连接

示意红板的 PWMA / PWMB / VCC 丝印与部分实物的 NC 丝印不同，不能将同一位置的焊盘名称直接套用。尤其核对 VM、GND、 休眠或使能端；STBY 并非所有 DRV8833 模块都采用的名字。

电池标称 7.4 V 不等于电机得到 6 V。核对电机与灯模块的实际供电、极性、共地和焊点后再上电，首次测试架空三轮。

DRV8833 官方芯片说明和数据手册
https://www.ti.com/product/DRV8833

# 05 推荐：交给本地 AI 刷写

### 不用自己逐条输入刷写命令。准备好文件、连接小车，把下面这段话交给能操作电脑的本地 AI 助手。

## 选什么 AI 工具

可使用 Codex、Claude Code、Trae、WorkBuddy 等本地 AI 助手；使用 DeepSeek 时，可搭配本地 Agent / Harness。无论选哪种，都要具备本机终端、文件和 USB 串口访问能力。只有网页聊天、无法操作本

### 机的 AI，不能直接替你刷写。

## 1. 准备依赖

安装所选本地 AI 工具，以及电脑端 Python 3。Windows 安装 Python 时勾选加入 PATH。刷写依赖 mpremote，可让 AI 帮你安装，不必自己研究命令。

Python 3 官方下载
https://www.python.org/downloads/windows/

交给 AI 安装的依赖命令：

py -m pip install --upgrade mpremote

## 2. 连接小车，给 AI 文件夹

### 用支持数据传输的 USB 线连接 CyberBrick 核心板，架空三轮。关闭占用串口的软件，把配套固件文件夹交给

AI，里面应有 boot.py、main.py、rokicar_core.py 三个文件。

## 3. 复制这段话交给 AI

“请帮我给 CyberBrick 核心板上传这个文件夹里的 RokiCar 三文件固件。先安装或检查 Python 与 mpremote，识别实际 USB 串口，确认板子已有 MicroPython；备份原程序和校准参数，然后上传三个文件 到设备根目录。不要改引脚和车灯程序，不要擦除 Flash。上传后逐份回读并核对文件，再重启。请告诉我是否

### 成功，并引导我检查 RokiCar 热点、手机连接和架空电机测试。如果遇到错误，请先诊断，不要盲目继续。”

## 最后由你确认

### 看到 RokiCar 热点，手机 App 能连接，架空测试电机和停车正常，才算完成。AI 负责文件写入与校验，实际 动作仍需要你观察。若工具要求授权访问串口或执行命令，按它的界面提示确认。

mpremote 官方说明（需要排查时再看）
https://docs.micropython.org/en/latest/reference/mpremote.html

如果没有可操作本机的 AI，可使用本指南最后一节的 Thonny 手动方式。

# 06 安装 App，校准后再落地

RokiCar 项目与公开下载入口
https://github.com/yinbaozong/RokiCar

Android 手机安装包：直接下载 APK
https://github.com/yinbaozong/RokiCar/releases/download/v0.7.0/RokiCar-Controller-v1.22-debug.apk
1. 在 Android 安装 APK，按系统提示允许对应来源安装。旧安装签名不一致时可能需要卸载旧版，卸载会清 除本地设置；当前没有原生 iOS 安装包。
2. 开机后连接 Wi-Fi RokiCar，密码 12345678。App 连接 ws://192.168.4.1/ws；“此网络没有互联网”的 提示是正常的。
3. 架空三轮，在 App 中逐个测试端口，映射实际右前、左前和后轮，再修正方向。不要仅凭 M1/M2 名字推 断 App 逻辑轮位。

### 4. 校准最低稳定起转 PWM 与轮速增益并保存；预览前进、横移与原地旋转，确认轮子不擦壳。

### 5. 验证松手停车、急停和连接中断后停车，再低速落地。横移歪斜先检查轮位、轮向与轮速，不靠提高速度掩 盖问题。


可拆卸顶盖可继续设计轻型相机底座或传感器配件

拓展前确认安装孔、支架和加强筋不会碰到电池与线束，并实测重心、承载和固定可靠性。照片里的相机另购；图传和云台控制不属 于基础功能。

复刻完成的标准：文件回读一致、断电重启正常、App 能连接、架空运动与停车正确，再进行低速落地验证。串口不存在先查数据线 与驱动；端口被占用先关其他工具；缺少模块先查文件名和根目录。

# 07 手动刷写：备用方式

### 先解压作品附件中的配套三文件固件包。这里是上传 Python 程序，不是烧录 .bin 镜像。核心板必须已有兼容

的 MicroPython 环境并能通过 USB 进入 REPL；不要为了传文件擦除 Flash 或刷通用 ESP32 镜像。

下载安装 Thonny：Windows 常规安装版自带电脑端 Python
https://thonny.org/

## 需要上传三份文件

文件 | 用途
boot.py | 有限初始化，正常返回后由 MicroPython 自动执行主程序
main.py | 网络通信、电机控制、灯光和启动入口
rokicar_core.py | 运动计算、指令解析和校准相关逻辑

### 1. 使用能传数据的 USB 线接电脑，关闭占用串口的软件，架空车轮或暂时断开电机电源。

2. Thonny 选择适合该板的 MicroPython（ESP32）解释器和实际串口。不要点击安装/更新底层 MicroPython。
3. 点击停止，必要时在 Shell 按 Ctrl+C，出现 >>> 后输入 import sys; print(sys.implementation)，确认能 进入 MicroPython。
4. 先将设备已有 boot.py、main.py、rokicar_core.py 和 rokicar_config.json 下载到电脑备份；没有的文件

### 记录为不存在。保留其他原厂文件。

5. 先将本包 boot.py 保存到设备根目录，再保存 rokicar_core.py 和 main.py。保留准确文件名，不只上传外 层文件夹；不要改成 .py.txt。

### 6. 从设备重新下载三份程序，与本地文件逐份比对内容或 SHA-256。不同则重传，不能仅凭保存成功判定完成。

### 7. 关闭工具连接，按复位键或断电重启，再检查热点和 App 控制。若重启循环或串口不稳定，先恢复稳定连接

，不继续盲写。

rokicar_config.json 是电机标定参数。已有校准文件应保留；新车可以不上传它，程序使用默认值，之后由 App 校准保存。它不是 平台所需的 CyberBrick 控制配置 JSON。

MicroPython 标准启动说明
https://docs.micropython.org/en/v1.26.0/reference/reset_boot.html

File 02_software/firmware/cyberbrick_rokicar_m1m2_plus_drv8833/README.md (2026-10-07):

# RokiCar 当前三文件固件

适用接收板 M1/M2 + 单块 DRV8833。将 boot.py、main.py、rokicar_core.py 三份文件放到设备根目录；boot.py 只做有限初始化，随后由标准 MicroPython 启动流程执行 main.py。电机与灯光逻辑不变，作者确认灯转接板接 D2 正常。

优先交给能够访问本机终端和 USB 串口的 AI：Codex、Claude Code、Trae、WorkBuddy 或 DeepSeek 搭配本地 Agent/Harness。安装 Python 和 mpremote，备份原程序与校准 JSON，上传后逐份回读核对，再硬复位并架空验收。

- [刷写教程](../../../05_docs/用户刷写教程.md)
- [给 AI 的提示词](../../../05_docs/交给AI刷写.txt)
- [简明复刻 PDF](../../../05_docs/RokiCar_复刻指南.pdf)

热点 RokiCar，密码 12345678，App 地址 ws://192.168.4.1/ws。index.html 和旧版说明属于历史学习内容，不作为当前控制网页入口。没有连接实车重新执行本轮刷写。

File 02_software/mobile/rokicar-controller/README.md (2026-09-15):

# RokiCar Android 控制器

这是三轮全向小车的 Vue 2 UniApp 原生 Android 控制端。它直接连接 CyberBrick 热点，不依赖互联网，也不会修改参考工程。

## 导入和运行

1. 手机连接 WiFi `RokiCar`，密码 `12345678`，允许系统继续使用“无互联网”的网络。
2. 在 HBuilderX 中选择“文件 -> 导入 -> 从本地目录导入”，选择本目录。
3. 打开 Android 手机的开发者选项和 USB 调试。
4. 在 HBuilderX 中选择“运行 -> 运行到手机或模拟器 -> 运行到 Android App 基座”。
5. App 会连接 `ws://192.168.4.1/ws`。顶部显示“已连接”后再操作。

正式 APK 需要可用的 DCloud 打包环境或账号。当前电脑没有安装 HBuilderX，因此工程已准备到可直接导入的状态，但尚未生成 APK。

## 四种控制方式

- **方向键**：按住前后左右平移；下方按钮原地左右旋转。
- **单摇杆**：方向决定平移方向，离中心越远越快；下方按钮控制旋转。
- **双摇杆**：左侧平移，右侧横轴旋转，可边走边转。
- **手机倾斜**：先以当前握持姿态校准，前后左右倾斜控制平移，下方按钮控制旋转。

慢速、标准、快速分别是 `35%`、`55%`、`75%`。所有方向都相对车头箭头，不是无头模式；核心板仍用 `SPEED_LIMIT=0.45` 做最终限速。

## 倾斜安全

- 启动后先采集约 `500ms` 作为当前水平零点。
- `3°` 内为死区，`3°` 到 `25°` 连续映射速度，超过 `25°` 保持当前档位上限。
- 加速度数据超过 `300ms` 未更新、相对倾角超过 `40°` 或加速度异常时立即解除并停车。
- 切换模式或速度、App 进入后台、锁屏、断网、WebSocket 断开时停车。
- 重连只恢复通信，绝不自动恢复运动或倾斜状态。

手机安装到车上时不要启用倾斜遥控。本版本只支持一个控制端，不支持车载手机和另一台遥控手机同时控制。

## 逻辑测试

电脑安装 Node.js 后在本目录运行：

```powershell
npm test
```

测试覆盖倾角计算、校准、死区、滤波、限幅、传感器超时和 12 字节二进制协议。

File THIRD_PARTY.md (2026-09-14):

# 第三方组件

MIT授权适用于本项目作者原创的代码、模型和文档，不改变第三方组件原有条款。

归档含Android Gradle wrapper、阿里云nuisdk-release.aar、ONNX Runtime、sherpa-onnx及唤醒模型等现有依赖；这些仍归各自权利人，不能因本仓库LICENSE而视为重新授权。当前AI功能在App1.21中关闭，保留依赖用于还原现有工程。原硬件参考模型中外购模块也不代表本项目原创。

现有资料未附齐第三方声明与模型来源，贡献者可帮助补全；本次公开不宣称第三方组件均属于MIT。

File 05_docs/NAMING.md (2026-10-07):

# 名称与版本

- 项目名称：**RokiCar**，大小写固定。
- 中文昵称：**洛奇小车**。
- 说明用语：六边形三轮全向机器人。
- 当前机械：V8；当前Android：1.22.0。

项目、APP、热点、源码目录与当前文档统一使用 RokiCar。

热点SSID已改为 `RokiCar`，默认密码仍为 `12345678`，控制地址仍为 `ws://192.168.4.1/ws`。Android应用ID改为 `com.rokicar.controller`，所以1.22会作为独立APP安装。升级时必须同时刷入新版固件并连接新的RokiCar热点。

远程仓库目前私有；MakerWorld文案不把私有仓库当作用户下载入口。

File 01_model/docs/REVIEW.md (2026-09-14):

V7 审核版：单侧8毫米宽抠手位；固定围边在此完全让开，原外顶面局部下沉0.7毫米。盖子下侧让空，形成2毫米净高，盖唇厚2.2毫米。中央顶面取消V6装饰线。内部结构不改。几何指甲通道为4毫米宽、1.2毫米厚，不代表实际手感或磁吸力验证。用户已确认V7，宣传图与项目资料已汇总在本包。

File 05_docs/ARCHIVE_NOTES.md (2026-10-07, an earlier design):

# 资料与历史说明

当前主线已更新到 V8，仓库公开，Android 保持 1.22.0。旧硬件学习指南和旧 SVG 保留历史用途；发生冲突时以根 README、D2 PNG 接线图、主固件与最新复刻 PDF 为准。

旧 V7 爆炸图和取盖剖面位于 history，不能用来判断 V8 的定位销、磁铁数量和公差。旧概念相机图已撤下。原整车参考 STEP 保持原样，不是 V8 全车重装配。

FILE_INDEX.tsv 和 SHA256SUMS.json 对应本次 Git 跟踪内容；哈希按仓库规范化字节生成，不含本机缓存与 private 配置。完整 ZIP 使用同一套字节，便于复核。

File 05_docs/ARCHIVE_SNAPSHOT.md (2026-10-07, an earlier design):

当前 FILE_INDEX.tsv 与 SHA256SUMS.json 已重新生成，覆盖本轮发布文件（不含索引和校验文件自身），不再使用旧 V7 快照。历史版本可从 Git 历史和旧 Release 查阅。

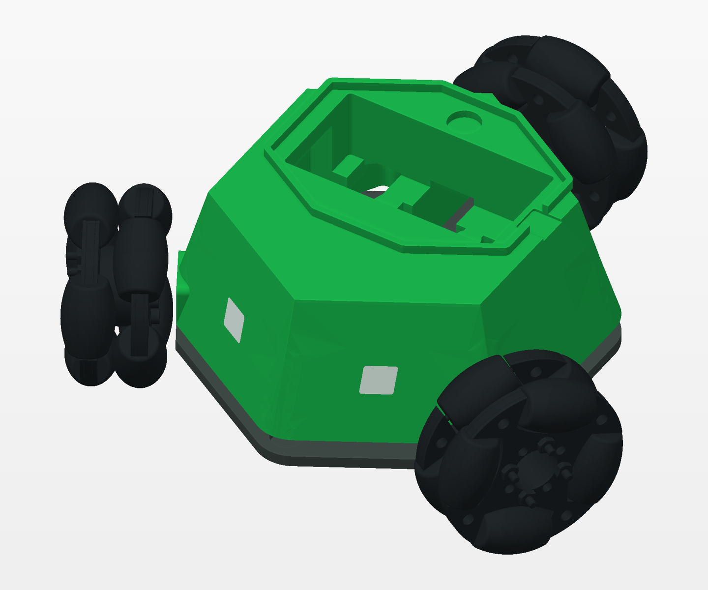
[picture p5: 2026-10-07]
01_model/images/02_open_shell.png

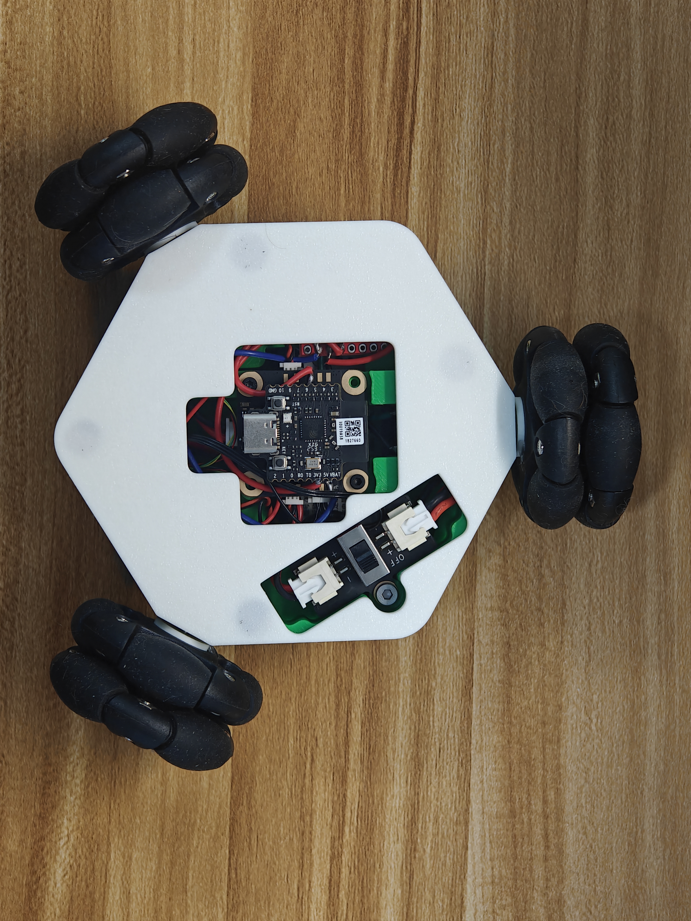
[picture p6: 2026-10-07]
04_media/04_bottom_real.jpg

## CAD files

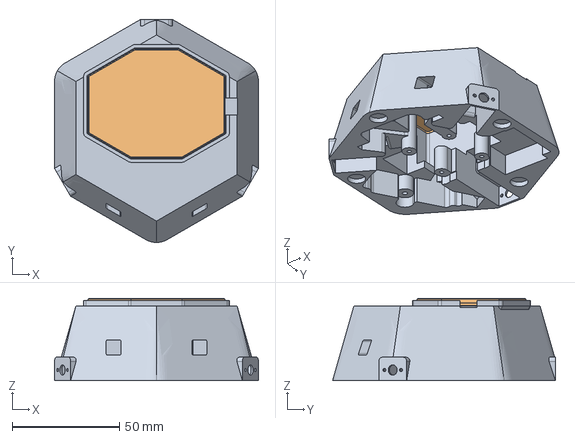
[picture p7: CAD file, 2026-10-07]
01_model/cad/03_shell_assembly.step
95.3 x 104.1 x 38.5 mm
01_shell
02_hatch

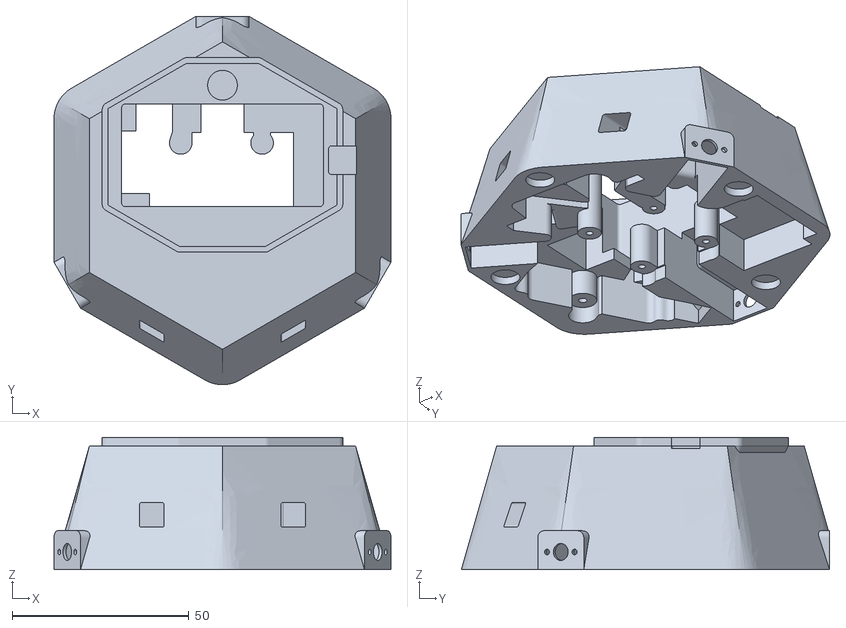
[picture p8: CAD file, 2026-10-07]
01_model/build/meshes/01_shell.stl
95.3 x 104.1 x 37.4

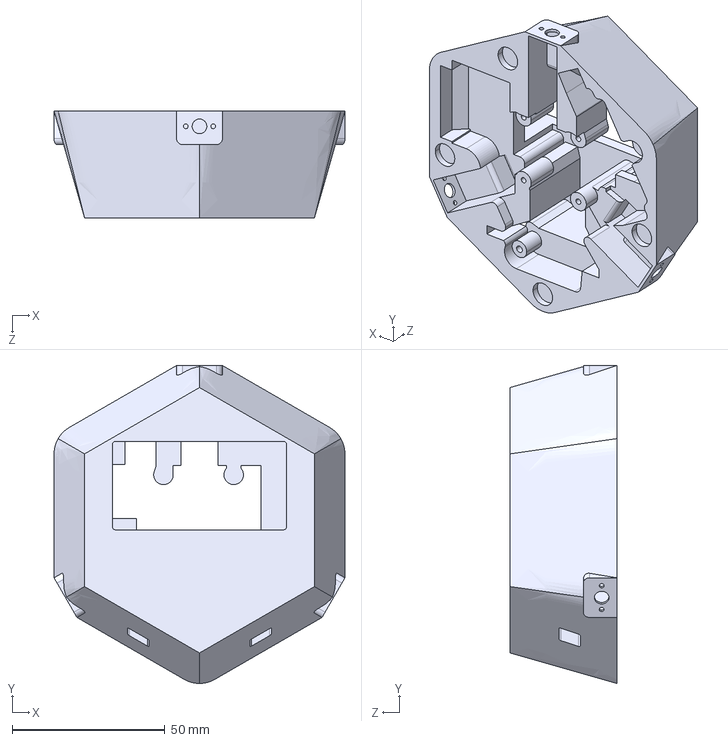
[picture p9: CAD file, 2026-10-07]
01_model/reference/original_shell.step
95.3 x 104.1 x 35.0 mm

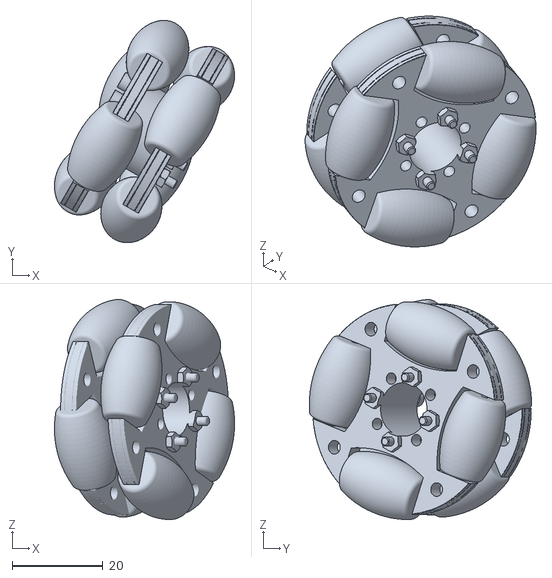
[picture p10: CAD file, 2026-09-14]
01_model/reference/render_context/original_2.stl
39.7 x 49.0 x 48.5

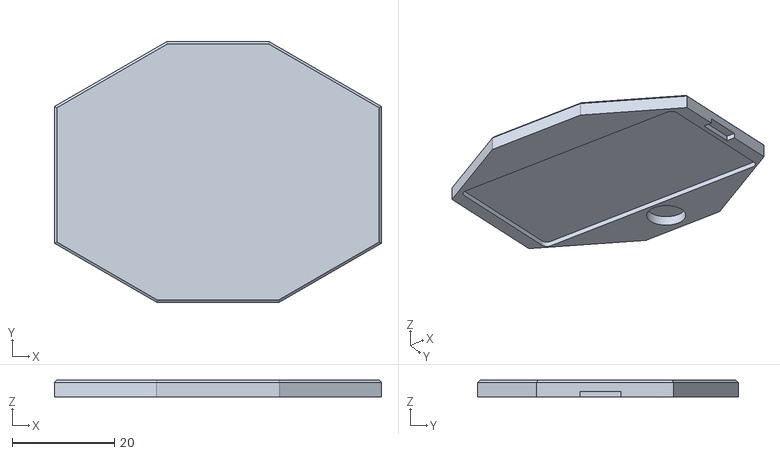
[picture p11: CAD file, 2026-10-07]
01_model/build/meshes/02_hatch.stl
64.0 x 51.0 x 3.30

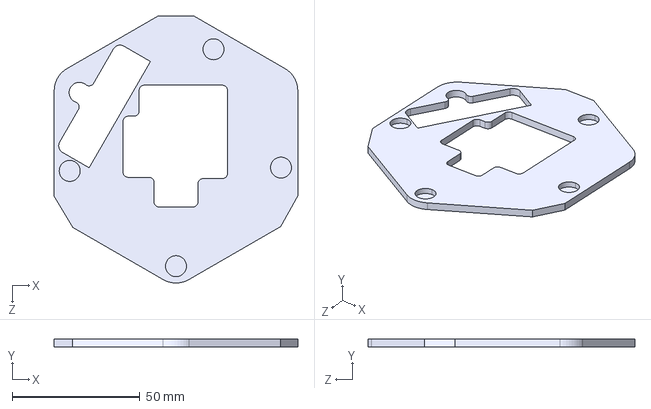
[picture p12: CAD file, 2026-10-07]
01_model/cad/04_original_base.step
95.3 x 3.00 x 104.4 mm

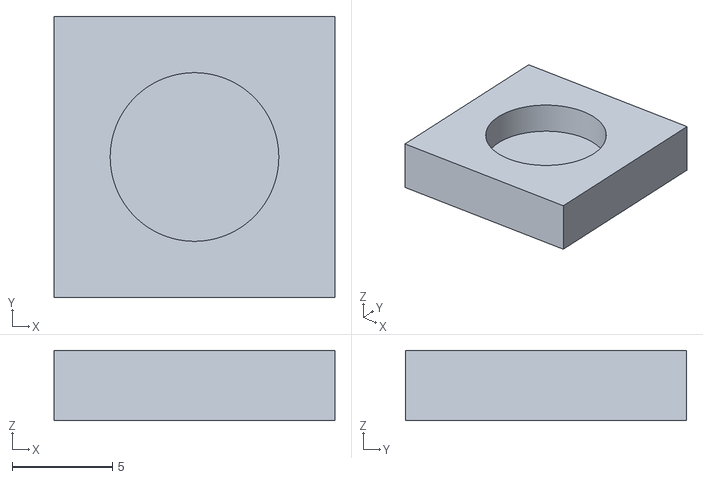
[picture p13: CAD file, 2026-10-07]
01_model/print/04_magnet_fit_coupon.stl
14.0 x 14.0 x 3.50

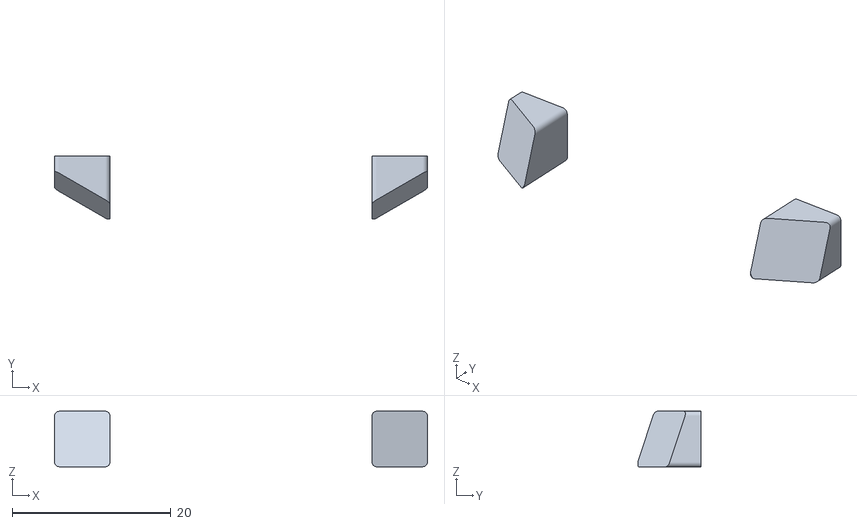
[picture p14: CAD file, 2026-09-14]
01_model/reference/render_context/original_14.stl
47.0 x 8.00 x 7.00

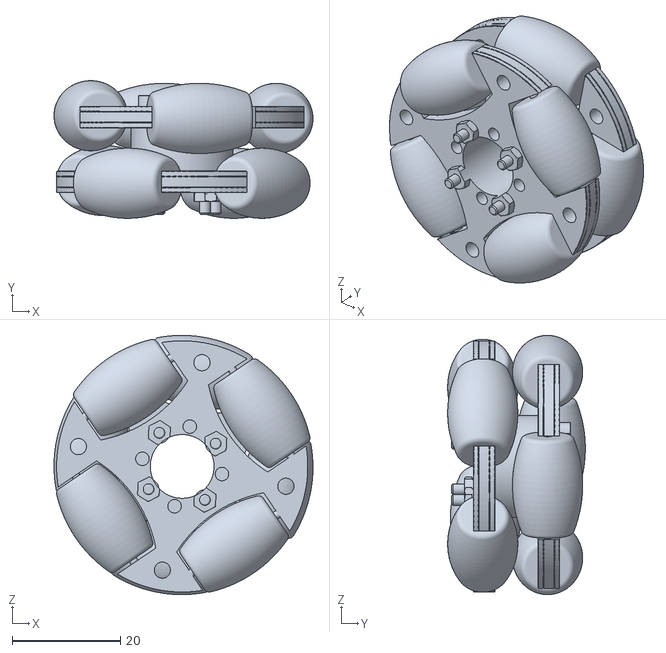
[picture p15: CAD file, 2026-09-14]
01_model/reference/render_context/original_3.stl
47.9 x 25.5 x 48.0

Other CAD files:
01_model/cad/02_hatch.step
01_model/print/02_hatch_print.stl
01_model/reference/render_context/original_1.stl
01_model/reference/render_context/original_0.stl
01_model/cad/01_shell.step

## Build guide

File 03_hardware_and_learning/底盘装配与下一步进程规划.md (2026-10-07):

> 历史学习资料：当前接线、灯口和轮位请以 [最新 D2 接线说明](../05_docs/HARDWARE_CONNECTIONS.md) 与 [接线图](RokiCar接线图_D2.png) 为准。

# 底盘装配与下一步进程规划

日期：2026-06-28

## 1. 当前底盘判断

你现在画出的底盘方向是正确的：三个轮子外伸，中心留出一块六边形平台。按定版轮心圆直径 135 mm、47 mm 全向轮计算，中心平台已经足够放下控制板和小型电机驱动板。

需要注意的是：不要把核心板、驱动板、电池、开关都压在同一层。这个车后面还要放手机和舵机，第一版应该优先保证低重心、好接线、好拆修。

## 2. 推荐分层

### 下层：动力与重物层

下层放这些：

- 三个电机和轮子。
- 电机驱动板。
- 电池。
- 主电源开关。
- 6 V 降压模块。

下层目标是把重物压低，减少手机和云台带来的晃动。

### 中层：控制层

中层放这些：

- CyberBrick 核心板。
- 排针或接线端子。
- 预留 I2C/舵机/电池电压检测接口。

中层用 M3 铜柱或打印柱撑起，建议离下层 25-30 mm。CyberBrick 核心板不要贴着电机驱动板放，留出 8-10 mm 空气间隙。

### 上层：手机与云台层

上层后面再做：

- 手机托盘。
- 舵机云台。
- 摄像头或手机固定结构。

这层先不要急着建复杂结构，等底盘能稳定运动后再加。

## 3. 具体摆放建议

坐标约定：两个前轮方向为车头，单后轮方向为车尾。

### CyberBrick 核心板

放在中层，靠近车体中心，略微偏后 5-10 mm。

建议方向：

- USB-C 朝车尾或侧边，方便插线和烧录。
- 天线区域不要被电池、金属螺丝柱、大片铜箔挡住。
- 核心板下面不要正对电机驱动芯片，减少热量和电机噪声影响。

建模占位建议先按 60 x 45 mm 做包络。如果你量到实际板子更小，再缩小安装孔。

### 电机驱动板

如果你买的是单块 3 路或 4 路电机驱动板，放在下层中心偏前，靠近三根电机线汇合的位置。

如果你用两个 DRV8833 双路模块：

- 第一块放在下层前半区，负责左右前轮。
- 第二块放在下层后半区，负责后轮，空出一个通道备用。

驱动板与 CyberBrick 之间用 6 根信号线连接，驱动板到电机的粗线尽量短。电机电源线和 CyberBrick 信号线不要长距离并排走。

建模占位建议：

- 单块 4 路驱动板：先按 45 x 35 mm 预留。
- DRV8833 小板：每块先按 25 x 20 mm 预留。
- 接线端子前方额外留 8-12 mm 插线空间。

### 电池

电池放下层，尽量低，建议放在中心偏后。

原因是后面手机、相机、舵机通常会让重心偏前，电池后移一点能配平。电池不要放到三轮支撑三角形外面。

建模占位建议先按 60 x 35 x 20 mm 预留，实际根据你买的 2S 电池调整。

### 开关与充电/电源接口

主开关放在侧边，不要放底部，不然每次开关都要把车拿起来。

推荐放在右侧或车尾侧边，开孔预留：

- 小拨动开关：约 13 x 8 mm。
- 船型开关：约 19 x 13 mm。

## 4. 这一版底板应该补的结构

底板现在下一步要加这些东西：

1. 三个电机安装长圆孔，每个方向允许 1-2 mm 微调。
2. 电机旁边加扎带孔，用来固定电机线。
3. 中心加 4 个 M3 铜柱孔，用来撑中层控制板。
4. 下层加驱动板安装孔，孔距不确定时先做 2.5 mm 腰孔。
5. 电池位置加两条绑带槽，宽 4-5 mm。
6. 侧边加电源开关孔。
7. 每个轮子附近检查 3-5 mm 转动避让，轮子滚轮不要擦到底板。

## 5. 下一步进程

### 第 1 步：做电子元件占位块

在 SolidWorks 里先不要建精细模型，只建几个简单长方体：

- CyberBrick 核心板包络。
- 电机驱动板包络。
- 电池包络。
- 降压模块包络。
- 开关包络。

每个占位块都要保留插线空间。插线空间比板子本体更容易被忘。

### 第 2 步：完成下层底板 V1

先只做下层底板，不做手机云台。下层底板要包含电机、驱动板、电池、开关、铜柱孔。

### 第 3 步：打印小样验证

不要直接打印完整最终版。先打印一个薄的安装验证版：

- 厚度 2 mm。
- 只验证电机孔、轮子避让、电池绑带槽、铜柱孔。
- 不追求强度。

### 第 4 步：电机空载测试

不装手机，不装上层，只接三电机和驱动板。确认：

- 三个电机都能正反转。
- PWM 调速正常。
- CyberBrick 不会因为电机启动而重启。

### 第 5 步：底盘低速落地测试

先限制最大 PWM 到 40%。测试顺序：

1. 原地旋转。
2. 前后移动。
3. 左右横移。
4. 斜向移动。

如果方向反了，先在程序里改符号，不要急着改结构。

### 第 6 步：做中层和手机层

底盘能稳定运动后，再加中层 CyberBrick 固定板和上层手机托盘。最后才加舵机云台。

## 6. 现在不要急着做的事

- 不要现在就做完整手机云台。
- 不要现在就追求外壳漂亮。
- 不要现在就加摄像头闭环。
- 不要现在就把所有孔都做死，驱动板、电池和开关都要留微调余量。

当前目标只有一个：让 135 mm 轮心圆底盘带三电机、驱动板、电池和 CyberBrick 稳定跑起来。

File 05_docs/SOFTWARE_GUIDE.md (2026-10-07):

# 软件与刷写入口

Android 1.22.0：应用 ID com.rokicar.controller。安装现有 APK，无需先编译；本次没有更改 App 版本或功能。

当前主固件为 `02_software/firmware/cyberbrick_rokicar_m1m2_plus_drv8833` 中的 boot.py、main.py、rokicar_core.py。本轮只修正 boot.py 为有限初始化，电机、灯光和协议保持不变。作者确认 LED 转接板 IN 接 D2，按最新实车图使用，不再套用旧文档的灯口描述。

- [优先阅读复刻 PDF](RokiCar_复刻指南.pdf)：AI 刷写优先，手动方法在最后。
- [完整用户刷写教程](用户刷写教程.md)
- [给本地 AI 的提示词](交给AI刷写.txt)
- [下载 Android APK](https://github.com/yinbaozong/RokiCar/releases/latest/download/RokiCar-Controller-v1.22-debug.apk)
- [下载三文件固件](https://github.com/yinbaozong/RokiCar/releases/latest/download/RokiCar-Firmware-20261008.zip)

主固件热点 RokiCar，密码 12345678，地址 ws://192.168.4.1/ws。保留实车校准 JSON；新车默认参数必须架空校准后保存。AI 网页、语音、图传和云台不是基础版当前可用功能。UniApp、双驱动与 Wi-Fi 演示目录属于历史/学习方案，不能混入当前主线。

当前本地启动回归、语法和辅助模块依赖检查通过。文件写入、自动启动和实际控制需在用户板子上按教程验收，本轮未执行实车刷写。

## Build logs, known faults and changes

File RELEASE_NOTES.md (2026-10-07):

# RokiCar V8 · 最新模型、固件与复刻资料

更新日期：2026-10-08。Android 保持 1.22.0。

- 外壳更新为 V8：取消定位销，围边加厚至 1.60 mm，顶盖每侧间隙 0.40 mm，仅一组磁吸。内部和轮组不变。
- Ø8×2 mm 磁铁整车 10 颗，电机螺丝 M1.6×3 共 6 颗；BT 自攻规格仍为试配建议。
- 三文件固件：boot.py 有限初始化，标准启动 main.py；电机、灯光和控制协议不变。保留作者确认的 D2 灯接法。
- 最新 D2 接线 PNG，真实内部与底部照片，实拍优化主封面和相机展示。
- 八页复刻 PDF：物料、图片、接线、装配、AI 刷写优先、手动备用、首次校准。
- 撤下旧相机/云台概念图，旧 V7 爆炸图与剖面只保留为 history。

下载：RokiCar-V8-Complete-20261008.zip 为完整仓库资料；Models 为模型；Firmware 为三文件程序和刷写说明；APK 可独立下载；Replication-Guide.pdf 为简明指南。

模型与本地启动检查不替代实物试打或实车刷写。按教程备份、回读校验、硬复位与架空验收。相机图传、云台和闭环自主导航未交付；RSSI 返航为实验功能。旧 v0.7.0 / V7 是历史发布。

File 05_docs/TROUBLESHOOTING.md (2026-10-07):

# 故障排查

| 现象 | 优先检查 |
|---|---|
| 手机找不到RokiCar热点 | 确认已刷入新版固件，并检查板卡供电和固件启动 |
| 连Wi-Fi但APP不连 | 确认保留无互联网网络，地址192.168.4.1/ws，避免其它客户端同时占用 |
| 轮子只响不转 | 架空检查电源及机械阻力，重新标定最低起转PWM，不盲目加大电压 |
| 前进变旋转／斜走 | 检查W1/W2/W3映射与各轮方向，再校准增益 |
| 第三轮不动 | 核对D1/GPIO21、D2/GPIO20、DRV8833 VM/GND及模块使能脚 |
| 灯不亮／颜色不对 | 按作者确认的 D2 图核对 IN、供电、共地和模块型号；保持现有固件，不猜改灯脚 |
| 磁吸盖弹开 | 检查极性、孔内胶、间隙和电池线挤压；V8 已取消定位销 |
| 盖子抠不开 | 检查8毫米缺口与盖下净空是否被支撑/毛边堵塞；不可连固定壳边强撬 |
| 底盖与车壳有间隙 | 原参考装配定位存在偏移；先确认实物装配面/紧固关系，勿按渲染图推断尺寸 |
| 返航有偏差 | 实验功能无定位闭环，轮滑与速度误差会累积 |

## 反馈模板

- 模型/APP/固件版本：
- 打印机、材料、喷嘴、层高（若相关）：
- 主板、驱动、电机、供电型号：
- 预期行为与实际行为：
- 复现步骤、照片、接线近照或日志：
- 是否架空可复现：

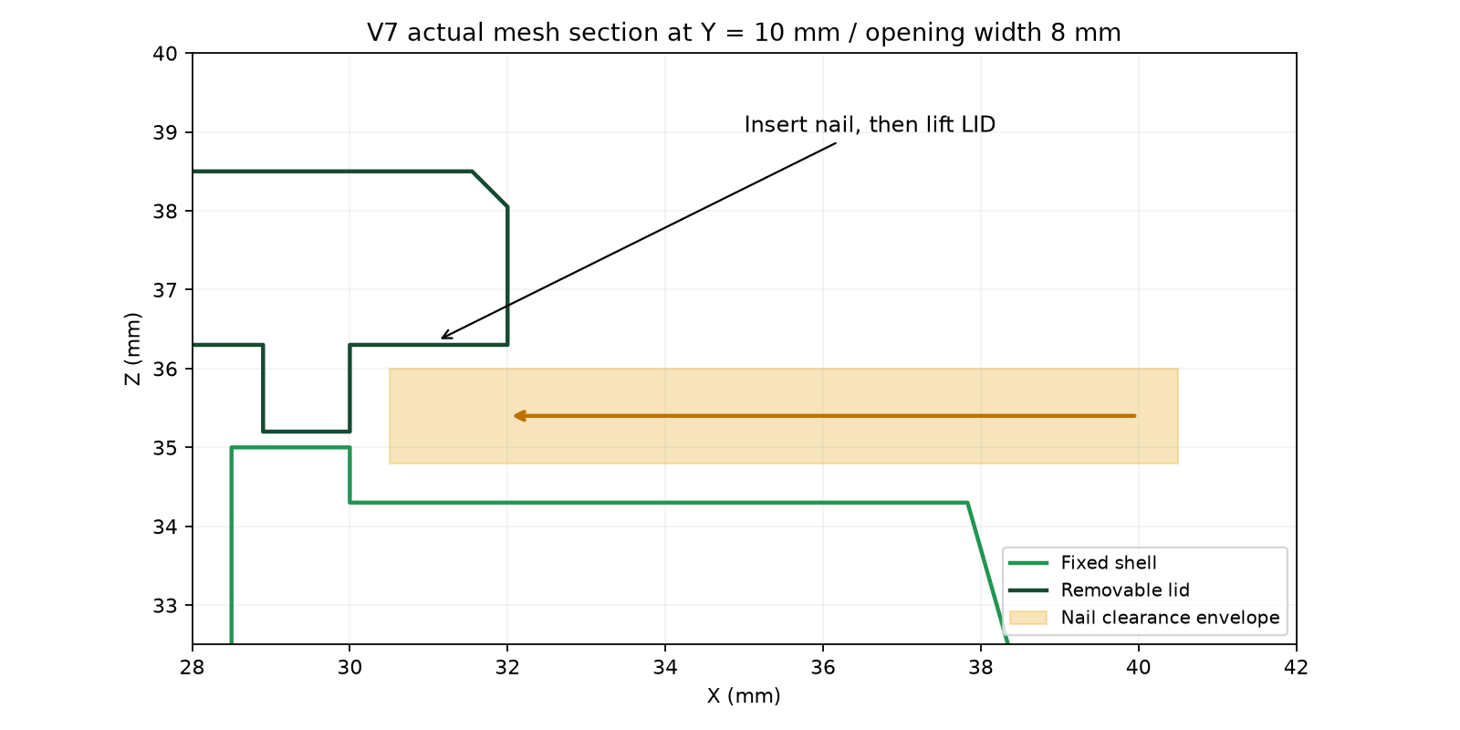
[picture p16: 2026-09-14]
01_model/images/history/02_grip_section.png

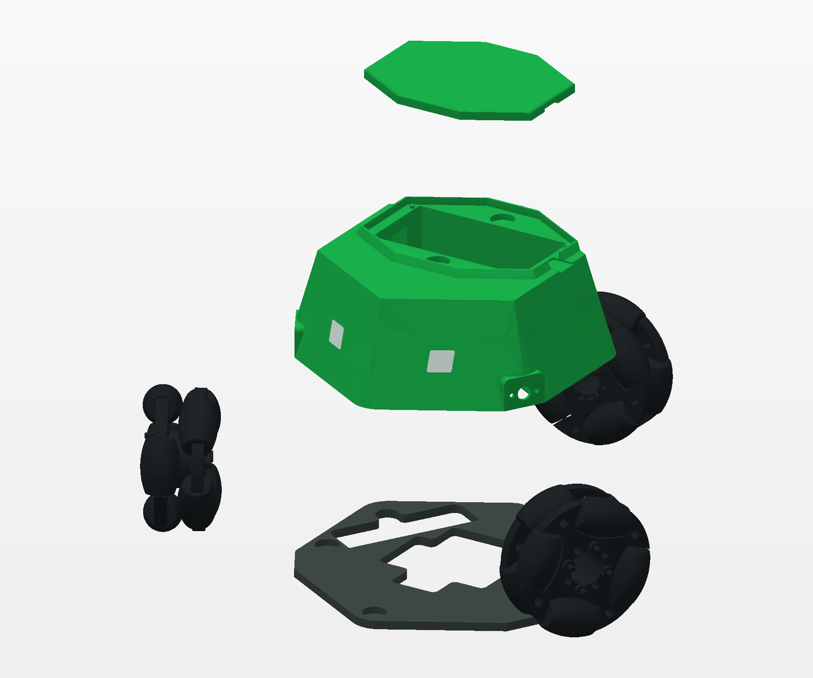
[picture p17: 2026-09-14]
04_media/history/04_exploded_cad.png

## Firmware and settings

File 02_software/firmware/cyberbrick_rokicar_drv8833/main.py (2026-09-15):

import gc
import math
import network
import socket
import time
from machine import Pin, PWM

try:
    import ujson as json
except ImportError:
    import json


AP_SSID = "RokiCar"
AP_PASSWORD = "12345678"
AP_IP = "192.168.4.1"

# CyberBrick Controller Core pin plan:
# S1/S2/S3/S4 signal pins are GPIO3/GPIO2/GPIO1/GPIO0.
# GPIO21/GPIO20 are used for the third motor on core-board side pads.
MOTOR_PINS = {
    "w1_left_front": (3, 2),   # DRV-A AIN1/AIN2
    "w2_right_front": (1, 0),  # DRV-A BIN1/BIN2
    "w3_rear": (21, 20),      # DRV-B AIN1/AIN2
}

# Change these signs if a wheel spins in the opposite direction during testing.
MOTOR_SIGN = {
    "w1_left_front": 1,
    "w2_right_front": 1,
    "w3_rear": 1,
}

PWM_FREQ = 1000
PWM_MAX = 65535
SPEED_LIMIT = 0.45       # First floor test: keep 0.35-0.50
ROT_GAIN = 0.75
COMMAND_TIMEOUT_MS = 500


HTML = """<!doctype html>
<html lang="zh-CN">
<head>
  <meta charset="utf-8">
  <meta name="viewport" content="width=device-width, initial-scale=1, user-scalable=no">
  <title>RokiCar Control</title>
  <style>
    * { box-sizing: border-box; touch-action: manipulation; }
    body { margin: 0; font-family: Arial, sans-serif; background: #f6f7f2; color: #1f2428; }
    main { min-height: 100vh; padding: 18px; display: grid; gap: 14px; align-content: start; }
    h1 { margin: 0; font-size: 26px; }
    h2 { margin: 0 0 10px; font-size: 18px; }
    .hint { color: #667078; line-height: 1.5; margin: 6px 0 0; }
    .card { background: #fff; border: 1px solid #d7ddd8; border-radius: 8px; padding: 14px; }
    .grid { display: grid; grid-template-columns: repeat(3, 1fr); gap: 10px; }
    button {
      min-height: 58px; border: 1px solid #aeb8b2; border-radius: 8px;
      background: #ffffff; font-size: 18px; color: #1f2428;
    }
    button:active { background: #dff3e8; transform: translateY(1px); }
    .stop { background: #fff0ed; border-color: #d8a8a0; }
    label { display: grid; grid-template-columns: 64px 1fr 48px; gap: 10px; align-items: center; margin: 8px 0; }
    input[type="range"] { width: 100%; accent-color: #168a5b; }
    .status { font-family: Consolas, monospace; white-space: pre-wrap; line-height: 1.5; }
  </style>
</head>
<body>
<main>
  <section>
    <h1>RokiCar</h1>
    <p class="hint">CyberBrick + DRV8833 三轮全向底盘测试。第一次请把车架空。</p>
  </section>

  <section class="card">
    <h2>移动</h2>
    <div class="grid">
      <button data-vx="-0.5" data-vy="0.5" data-rot="0">左前</button>
      <button data-vx="0" data-vy="0.7" data-rot="0">前进</button>
      <button data-vx="0.5" data-vy="0.5" data-rot="0">右前</button>
      <button data-vx="-0.7" data-vy="0" data-rot="0">左移</button>
      <button class="stop" data-vx="0" data-vy="0" data-rot="0">停止</button>
      <button data-vx="0.7" data-vy="0" data-rot="0">右移</button>
      <button data-vx="0" data-vy="0" data-rot="-0.7">左转</button>
      <button data-vx="0" data-vy="-0.7" data-rot="0">后退</button>
      <button data-vx="0" data-vy="0" data-rot="0.7">右转</button>
    </div>
  </section>

  <section class="card">
    <h2>微调</h2>
    <label>Vx <input id="vx" type="range" min="-1" max="1" step="0.05" value="0"><span id="vxv">0</span></label>
    <label>Vy <input id="vy" type="range" min="-1" max="1" step="0.05" value="0"><span id="vyv">0</span></label>
    <label>Rot <input id="rot" type="range" min="-1" max="1" step="0.05" value="0"><span id="rotv">0</span></label>
    <button id="send">发送</button>
  </section>

  <section class="card">
    <div id="status" class="status">未连接</div>
  </section>
</main>

<script>
const statusBox = document.getElementById("status");
const sliders = ["vx", "vy", "rot"].map(id => document.getElementById(id));

function updateLabels() {
  document.getElementById("vxv").textContent = document.getElementById("vx").value;
  document.getElementById("vyv").textContent = document.getElementById("vy").value;
  document.getElementById("rotv").textContent = document.getElementById("rot").value;
}

async function send(vx, vy, rot) {
  try {
    const res = await fetch(`/cmd?vx=${vx}&vy=${vy}&rot=${rot}&t=${Date.now()}`);
    const data = await res.json();
    statusBox.textContent = JSON.stringify(data, null, 2);
  } catch (err) {
    statusBox.textContent = "请求失败: " + err;
  }
}

document.querySelectorAll("button[data-vx]").forEach(btn => {
  btn.addEventListener("click", () => {
    document.getElementById("vx").value = btn.dataset.vx;
    document.getElementById("vy").value = btn.dataset.vy;
    document.getElementById("rot").value = btn.dataset.rot;
    updateLabels();
    send(btn.dataset.vx, btn.dataset.vy, btn.dataset.rot);
  });
});

sliders.forEach(slider => slider.addEventListener("input", updateLabels));
document.getElementById("send").addEventListener("click", () => {
  send(document.getElementById("vx").value, document.getElementById("vy").value, document.getElementById("rot").value);
});
updateLabels();
setInterval(() => send(0, 0, 0), 2000);
</script>
</body>
</html>
"""


class Motor:
    def __init__(self, pin_a, pin_b, sign=1):
        self.a = PWM(Pin(pin_a), freq=PWM_FREQ)
        self.b = PWM(Pin(pin_b), freq=PWM_FREQ)
        self.sign = sign
        self.set(0)

    def _duty(self, value):
        value = max(0, min(1, abs(value)))
        return int(PWM_MAX * value)

    def _write(self, pwm, value):
        duty = self._duty(value)
        if hasattr(pwm, "duty_u16"):
            pwm.duty_u16(duty)
        else:
            pwm.duty(int(duty * 1023 / PWM_MAX))

    def set(self, speed):
        speed = max(-1, min(1, speed * self.sign))
        if speed > 0:
            self._write(self.a, speed)
            self._write(self.b, 0)
        elif speed < 0:
            self._write(self.a, 0)
            self._write(self.b, -speed)
        else:
            self._write(self.a, 0)
            self._write(self.b, 0)


motors = {
    name: Motor(pins[0], pins[1], MOTOR_SIGN[name])
    for name, pins in MOTOR_PINS.items()
}

state = {
    "vx": 0,
    "vy": 0,
    "rot": 0,
    "w1": 0,
    "w2": 0,
    "w3": 0,
    "limit": SPEED_LIMIT,
    "count": 0,
    "last_ms": 0,
}


def stop_all():
    for motor in motors.values():
        motor.set(0)
    state["w1"] = 0
    state["w2"] = 0
    state["w3"] = 0


def mix_omni(vx, vy, rot):
    w1 = -0.5 * vx - 0.866 * vy + ROT_GAIN * rot
    w2 = -0.5 * vx + 0.866 * vy + ROT_GAIN * rot
    w3 =  1.0 * vx              + ROT_GAIN * rot
    scale = max(1, abs(w1), abs(w2), abs(w3))
    return (w1 / scale, w2 / scale, w3 / scale)


def drive(vx, vy, rot):
    w1, w2, w3 = mix_omni(vx, vy, rot)
    w1 *= SPEED_LIMIT
    w2 *= SPEED_LIMIT
    w3 *= SPEED_LIMIT
    motors["w1_left_front"].set(w1)
    motors["w2_right_front"].set(w2)
    motors["w3_rear"].set(w3)
    state["vx"] = round(vx, 3)
    state["vy"] = round(vy, 3)
    state["rot"] = round(rot, 3)
    state["w1"] = round(w1, 3)
    state["w2"] = round(w2, 3)
    state["w3"] = round(w3, 3)
    state["count"] += 1
    state["last_ms"] = time.ticks_ms()


def start_ap():
    ap = network.WLAN(network.AP_IF)
    ap.active(True)
    try:
        ap.config(essid=AP_SSID, password=AP_PASSWORD, authmode=network.AUTH_WPA_WPA2_PSK)
    except Exception:
        ap.config(essid=AP_SSID, password=AP_PASSWORD)
    ap.ifconfig((AP_IP, "255.255.255.0", AP_IP, AP_IP))
    while not ap.active():
        time.sleep(0.1)
    return ap


def parse_query(path):
    values = {}
    if "?" not in path:
        return values
    query = path.split("?", 1)[1].split(" ", 1)[0]
    for part in query.split("&"):
        if "=" in part:
            key, value = part.split("=", 1)
            values[key] = value
    return values


def response(conn, status, content_type, body):
    if isinstance(body, str):
        body = body.encode("utf-8")
    header = (
        "HTTP/1.1 {}\r\n"
        "Content-Type: {}\r\n"
        "Content-Length: {}\r\n"
        "Connection: close\r\n"
        "Cache-Control: no-store\r\n\r\n"
    ).format(status, content_type, len(body))
    conn.send(header.encode("utf-8"))
    conn.send(body)


def handle_request(conn):
    request = conn.recv(1024).decode()
    first = request.split("\r\n", 1)[0]
    path = first.split(" ")[1] if " " in first else "/"

    if path.startswith("/cmd"):
        q = parse_query(first)
        vx = float(q.get("vx", 0))
        vy = float(q.get("vy", 0))
        rot = float(q.get("rot", 0))
        drive(vx, vy, rot)
        response(conn, "200 OK", "application/json", json.dumps(state))
    else:
        response(conn, "200 OK", "text/html; charset=utf-8", HTML)


def main():
    stop_all()
    ap = start_ap()
    print("AP:", AP_SSID, AP_PASSWORD, ap.ifconfig())

    addr = socket.getaddrinfo("0.0.0.0", 80)[0][-1]
    server = socket.socket()
    server.setsockopt(socket.SOL_SOCKET, socket.SO_REUSEADDR, 1)
    server.bind(addr)
    server.listen(2)
    server.settimeout(0.2)
    print("Open http://{}/".format(AP_IP))

    while True:
        try:
            conn, _ = server.accept()
            try:
                handle_request(conn)
            finally:
                conn.close()
                gc.collect()
        except OSError:
            pass

        if state["last_ms"] and time.ticks_diff(time.ticks_ms(), state["last_ms"]) > COMMAND_TIMEOUT_MS:
            stop_all()
            state["last_ms"] = 0


main()

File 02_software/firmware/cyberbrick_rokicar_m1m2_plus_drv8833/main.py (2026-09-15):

import gc
import os
import time

try:
    import usocket as socket
except ImportError:
    import socket
try:
    import ujson as json
except ImportError:
    import json
try:
    import ubinascii as binascii
except ImportError:
    import binascii
try:
    import uhashlib as hashlib
except ImportError:
    import hashlib
try:
    import neopixel
except ImportError:
    neopixel = None

import machine
from machine import Pin, PWM, WDT
from rokicar_core import (
    MSG_DRIVE, MSG_GAINS, MSG_PING, MSG_SAVE, MSG_SQUARE, MSG_STOP,
    MSG_WHEEL_MAP, MSG_WHEEL_TEST, MSG_MOTOR_TEST, MSG_MOTOR_MODEL,
    MSG_QUERY_CONFIG,
    SquareRunner, decode_command, gains_as_float, is_newer_sequence,
    linearize_motor_command, normalize_wheels, validate_gains,
    validate_min_duties, validate_motor_test, validate_wheel_map,
    validate_wheel_test,
)

AP_SSID = "RokiCar"
AP_PASSWORD = "12345678"
AP_IP = "192.168.4.1"
RGB_LED_PIN = 8
ACCESSORY_LED_PIN = 3  # S1; D1/D2 remain assigned to W3.
MSG_LIGHT = 12
accessory_rgb = (0, 0, 0)
accessory_led = None
try:
    if neopixel:
        accessory_led = neopixel.NeoPixel(Pin(ACCESSORY_LED_PIN), 4)
        accessory_led.fill(accessory_rgb)
        accessory_led.write()
except Exception:
    accessory_led = None
M1_AIN1, M1_AIN2 = 4, 5
M2_AIN1, M2_AIN2 = 6, 7
W3_AIN1, W3_AIN2 = 21, 20

PWM_FREQ = 1000
PWM_MAX = 65535
SPEED_LIMIT = 0.45
ROT_GAIN = 0.75
COMMAND_TIMEOUT_MS = 500
SOCKET_TIMEOUT_S = 0.1
GC_PERIOD_MS = 2000
WDT_TIMEOUT_MS = 2000
CONFIG_PATH = "rokicar_config.json"
CONFIG_TEMP_PATH = "rokicar_config.tmp"
CONFIG_VERSION = 2
MODE_IDLE, MODE_MANUAL, MODE_SQUARE, MODE_TEST = 0, 1, 2, 3


class Led:
    def __init__(self):
        self.last = None
        self.np = None
        self.pin = None
        try:
            self.np = neopixel.NeoPixel(Pin(RGB_LED_PIN), 1) if neopixel else None
            if not self.np:
                self.pin = Pin(RGB_LED_PIN, Pin.OUT)
        except Exception:
            self.pin = None

    def set(self, color):
        if color == self.last:
            return
        self.last = color
        try:
            if self.np:
                self.np[0] = color
                self.np.write()
            elif self.pin:
                self.pin.value(1 if color != (0, 0, 0) else 0)
        except Exception:
            pass


class Motor:
    def __init__(self, first, second):
        self.first = PWM(Pin(first), freq=PWM_FREQ)
        self.second = PWM(Pin(second), freq=PWM_FREQ)
        self.stop()

    def duty(self, pwm, value):
        value = max(0, min(1, value))
        duty = int(PWM_MAX * value)
        if hasattr(pwm, "duty_u16"):
            pwm.duty_u16(duty)
        else:
            pwm.duty(int(duty * 1023 / PWM_MAX))

    def set_raw(self, value):
        if value > 0:
            self.duty(self.first, value)
            self.duty(self.second, 0)
        elif value < 0:
            self.duty(self.first, 0)
            self.duty(self.second, -value)
        else:
            self.stop()

    def set(self, value, min_duty=0):
        self.set_raw(linearize_motor_command(value, min_duty, SPEED_LIMIT))

    def stop(self):
        self.duty(self.first, 0)
        self.duty(self.second, 0)


led = Led()
m1 = Motor(M1_AIN1, M1_AIN2)
m2 = Motor(M2_AIN1, M2_AIN2)
w3 = Motor(W3_AIN1, W3_AIN2)
motors = (m1, m2, w3)
square = SquareRunner(1600, 250, 550)
state = {
    "mode": MODE_IDLE, "gains": (1000, 1000, 1000), "last_cmd": 0,
    "wheel_map": (1, 2, -3), "min_duty": (0, 0, 0), "test_until": 0,
    "vector": (0, 0, 0), "wheels": (0, 0, 0),
    "last_seen": 0,
    "last_seq": None, "received": 0, "dropped": 0, "errors": 0,
    "reset": machine.reset_cause(), "last_error": "",
}
ws_conn = None
ws_buffer = bytearray()
last_gc = 0
wdt = None


def hard_stop():
    m1.stop()
    m2.stop()
    w3.stop()


def stop_all():
    square.stop()
    hard_stop()
    state["mode"] = MODE_IDLE
    state["vector"] = (0, 0, 0)
    state["wheels"] = (0, 0, 0)


def drive(vx, vy, rot):
    wheels = normalize_wheels(vx / 1000.0, vy / 1000.0, rot / 1000.0,
                              ROT_GAIN, gains_as_float(state["gains"]))
    physical = [0, 0, 0]
    for wheel, mapping in enumerate(state["wheel_map"]):
        physical[abs(mapping) - 1] = wheels[wheel] * (1 if mapping > 0 else -1)
    for index, value in enumerate(physical):
        motors[index].set(value, state["min_duty"][index] / 1000.0)
    state["vector"] = (vx, vy, rot)
    state["wheels"] = tuple(int(value * 1000) for value in physical)


def load_config():
    try:
        with open(CONFIG_PATH, "r") as file:
            config = json.loads(file.read())
            state["gains"] = validate_gains(config.get("gains"))
            mapping = validate_wheel_map(config.get("wheel_map"))
            if int(config.get("version", 1)) < CONFIG_VERSION:
                mapping = tuple(-value if abs(value) == 3 else value for value in mapping)
            state["wheel_map"] = mapping
            state["min_duty"] = validate_min_duties(config.get("min_duty"))
            if int(config.get("version", 1)) < CONFIG_VERSION:
                save_config()
    except Exception:
        state["gains"] = (1000, 1000, 1000)
        state["wheel_map"] = (1, 2, -3)
        state["min_duty"] = (0, 0, 0)


def save_config():
    try:
        with open(CONFIG_TEMP_PATH, "w") as file:
            file.write(json.dumps({"version": CONFIG_VERSION,
                                   "gains": list(state["gains"]),
                                   "wheel_map": list(state["wheel_map"]),
                                   "min_duty": list(state["min_duty"])}))
        try:
            os.rename(CONFIG_TEMP_PATH, CONFIG_PATH)
        except OSError:
            try:
                os.remove(CONFIG_PATH)
            except OSError:
                pass
            os.rename(CONFIG_TEMP_PATH, CONFIG_PATH)
        return True
    except Exception:
        state["errors"] += 1
        return False


def start_ap():
    import network
    ap = network.WLAN(network.AP_IF)
    try:
        ap.active(False)
        time.sleep_ms(100)
    except Exception:
        pass
    ap.active(True)
    try:
        ap.config(essid=AP_SSID, password=AP_PASSWORD, authmode=network.AUTH_WPA_WPA2_PSK)
    except Exception:
        ap.config(essid=AP_SSID, password=AP_PASSWORD)
    ap.ifconfig((AP_IP, "255.255.255.0", AP_IP, AP_IP))


def write_all(conn, data, timeout=0.2):
    try:
        conn.settimeout(timeout)
        conn.write(data)
        conn.settimeout(SOCKET_TIMEOUT_S)
        return True
    except Exception:
        return False


def reply(conn, status, content_type, body=b""):
    if isinstance(body, str):
        body = body.encode()
    header = "HTTP/1.1 {}\r\nContent-Type: {}\r\nContent-Length: {}\r\nConnection: close\r\nCache-Control: no-store\r\n\r\n".format(status, content_type, len(body)).encode()
    write_all(conn, header + body)
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

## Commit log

2026-09-14 Publish RIFT V7 models, controller, firmware and project documentation
    [01_shell.step, 01_shell.stl, 01_shell_print.stl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]
2026-09-15 Rename project, app and firmware to RokiCar
    [FILE_INDEX.tsv]
2026-10-07 Update V8 models, firmware startup, D2 wiring and replication guide
    [01_shell.step, 01_shell.stl, 01_shell_print.stl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]
2026-10-11 Add English README with language switch links
